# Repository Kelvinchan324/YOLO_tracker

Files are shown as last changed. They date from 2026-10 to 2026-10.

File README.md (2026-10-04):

# YOLO Camera Tracker

Mechanical design files for a two-axis camera and sensor tracker intended for
YOLO-based object-tracking projects.

## Teaching materials

- [`Workshop: Build Your Own YOLO Tracker`](teaching_materials/Workshop_Build_Your_Own_YOLO_Tracker.pdf)
  - the complete 65-page assembly, wiring, calibration, and testing guide.

## Gimbal control software

The [`software`](software) directory contains a Raspberry Pi controller for
the two STS3215 motors used by the workshop tracker. It uses servo ID `1` for
yaw and servo ID `2` for pitch, reads each unit's current center position, and
supports manual arrow-key control through the ESP32 driver's serial-forwarding
mode. The [software instructions](software/README.md) include a dedicated
Raspberry Pi Python and `scservo_sdk` setup section; read it before powering
the motors.

## CAD contents

The [`cad`](cad) directory contains the original SolidWorks models and
assemblies, along with neutral CAD exports where available.

- `cad/camera tracker with laser/` — current SolidWorks tracker parts and the
  `camer_tracker.SLDASM` top-level assembly.
- `cad/3D printing files/` — the grouped design files previously packaged as
  the sharing revision.
- `cad/educational version/` — simplified educational tracker design, including the main
  `camer_tracker_easy.SLDASM` assembly and electronics enclosure.
- `cad/distance_sensor-1.snapshot.12/` — distance-sensor reference model,
  images, datasheet, and STEP files.

## File formats

| Extension | Purpose |
| --- | --- |
| `.SLDASM` | SolidWorks assembly |
| `.SLDPRT` | SolidWorks part |
| `.STEP` | Neutral CAD exchange file |

SolidWorks assemblies reference their part files by name. Keep the relevant
assembly and its component files together when downloading or moving them.

## Getting started

For the camera tracker with laser, open
`cad/camera tracker with laser/camer_tracker.SLDASM` in SolidWorks. For the
simplified design, open `cad/educational version/camer_tracker_easy.SLDASM`.

Archive files that duplicated folders already included in this repository were
left out to avoid storing the same large binary files twice.

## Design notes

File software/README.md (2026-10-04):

# STS3215 Gimbal Controller

This controller follows the workshop setup:

- yaw motor: STS3215 servo ID `1`
- pitch motor: STS3215 servo ID `2`
- connection: ESP32 servo driver in `SERIAL_FORWARDING` mode
- serial device: `/dev/ttyUSB0`
- baud rate: `115,200`

The two motors are daisy-chained. The ESP32 driver is connected to the
Raspberry Pi by USB-C and powered separately by the 12 V servo supply.

## Safety before running

1. Assemble the gimbal and connect the servo cables in the orientation shown
   in the workshop notes.
2. Position the camera approximately forward and level by hand.
3. Keep hands and loose cables clear of the gears.
4. Power the ESP32 servo driver with the correct 12 V supply.
5. Confirm its display detects servo IDs `1` and `2` and enters
   `SERIAL_FORWARDING` mode.

The program reads the current positions on startup and treats them as the
center. It does not command either motor until you press a movement key.

## Install

On the Raspberry Pi:

```bash
cd software
python3 -m venv .venv
source .venv/bin/activate
python3 -m pip install -r requirements.txt
```

## Raspberry Pi control with Python and `scservo_sdk`

The controller uses the Feetech `scservo_sdk` package directly. The workshop
ESP32 board forwards commands at `115200` baud; this differs from the
STS3215's direct-bus factory baud rate. The Raspberry Pi port can change when
USB devices are reconnected, so find it before running the program:

```bash
dmesg | grep -i cp210x
python3 -m serial.tools.list_ports
ls -l /dev/ttyUSB*
```

Look for the CP210x adapter and use the corresponding device, commonly
`/dev/ttyUSB0` or `/dev/ttyUSB1`. Test communication without moving either
motor:

```bash
python3 gimbal_controller.py \
  --port /dev/ttyUSB0 \
  --baudrate 115200 \
  --calibrate-only
```

The essential `scservo_sdk` pattern used by the controller is:

```python
from scservo_sdk import COMM_SUCCESS, PortHandler, sms_sts

port = PortHandler("/dev/ttyUSB0")
servos = sms_sts(port)

if not port.openPort():
    raise RuntimeError("Could not open the serial port")

try:
    if not port.setBaudRate(115200):
        raise RuntimeError("Could not set the ESP32 forwarding baud rate")

    # ID 1 is yaw; ID 2 is pitch.
    yaw_position, result, error = servos.ReadPos(1)
    if result != COMM_SUCCESS or error:
        raise RuntimeError("Could not read yaw servo")

    pitch_position, result, error = servos.ReadPos(2)
    if result != COMM_SUCCESS or error:
        raise RuntimeError("Could not read pitch servo")

    print(f"Yaw center: {yaw_position}, pitch center: {pitch_position}")

    # WritePosEx(servo_id, target_position, speed, acceleration)
    # Use measured, mechanically safe targets between 0 and 4095.
    result, error = servos.WritePosEx(1, yaw_position, 500, 50)
    if result != COMM_SUCCESS or error:
        raise RuntimeError("Could not command yaw servo")
finally:
    port.closePort()
```

Use `ReadPos()` to obtain each tracker's unique center before commanding any
movement. `WritePosEx()` accepts the servo ID, a target from `0` to `4095`,
speed, and acceleration. The full `gimbal_controller.py` wraps these calls
with arrow-key input, limit checking, communication-error reporting, and
automatic serial-port cleanup.

If the Raspberry Pi reports a serial-port permission error, add the current
user to the `dialout` group and then sign out and back in:

```bash
sudo usermod -aG dialout "$USER"
```

## Calibrate and control

First read the two center positions without moving the gimbal:

```bash
python3 gimbal_controller.py --calibrate-only
```

Record the displayed yaw and pitch values, as required by the workshop notes.
Then start keyboard control:

```bash
python3 gimbal_controller.py
```

Controls:

- Left/Right: yaw
- Up/Down: pitch
- `C`: return to the center recorded at startup
- `R`: use the current measured positions as new centers
- `P`: display the current measured positions
- `Esc` or `Q`: quit

If an axis moves in the opposite direction, use `--invert-yaw` or
`--invert-pitch`. To limit travel for a particular build, set safe position
ranges. For example:

```bash
python3 gimbal_controller.py \
  --yaw-min 100 --yaw-max 4000 \
  --pitch-min 1800 --pitch-max 3100
```

Run `python3 gimbal_controller.py --help` for all options, including motor
IDs, serial port, step size, speed, and acceleration.

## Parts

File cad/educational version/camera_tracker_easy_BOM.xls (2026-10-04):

ITEM NO. | PART NUMBER | TYPE | QTY. | DESCRIPTION | Link
1 | camera_case | 3D print | 1
2 | camera_cover | 3D print | 1
3 | camera_tracker_bearing_mount | 3D print | 1
4 | U_mount | 3D print | 1
5 | camer_tracker_base_cover | 3D print | 1
6 | base_bearing_cover | 3D print | 1
7 | base_gear_bigger | 3D print | 1
8 | base_gear_smaller_easy | 3D print | 1
9 | camera_tracker_base | 3D print | 1
10 | electronics_box | 3D print | 1
11 | electronics_box_cover | 3D print | 1
12 | ENGG1101_webcam | Electronics | 1
13 | servoFeetechSTS3215_tracker | Electronics | 2
14 | STS3215_metal_horn_tracker | Electronics | 2
15 | 30_42_7_bearing | Bearing | 1
16 | M3*6 Screws | Screws | 10
17 | M3*8 Screws | Screws | 8
18 | M3*15 Screws | Screws | 2
19 | M3*30 Screws | Screws | 4
20 | Servo motor Screws Pack | Screws | 4
21 | M3 Nuts | Nuts | 4
22 | Monitor | Control & Display | 1
23 | Keyboard & Mouse | Control & Display | 1
24 | Micro HTMI Cable | Control & Display | 1
74 | RASPBERRY_PI_5 |  | 1

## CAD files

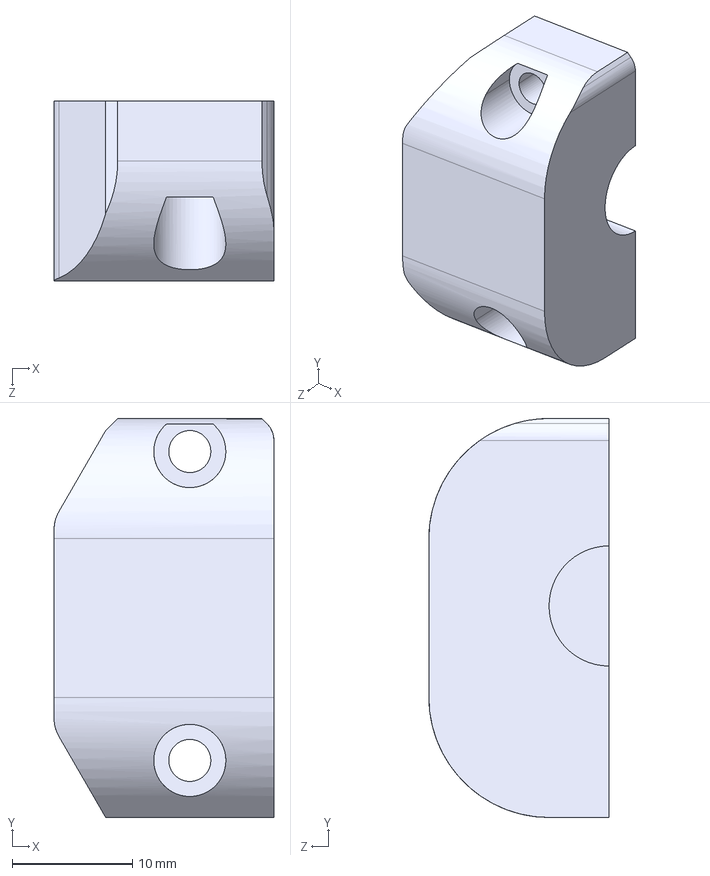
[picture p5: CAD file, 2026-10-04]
cad/camera_tracker_bearing_mount.STEP
18.3 x 33.2 x 15.0 mm

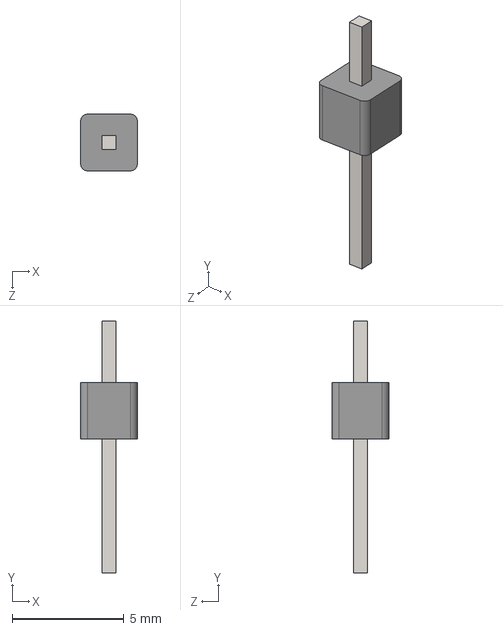
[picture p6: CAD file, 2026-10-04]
cad/distance_sensor-1.snapshot.12/STEP/headerPin.STEP
2.54 x 11.3 x 2.54 mm

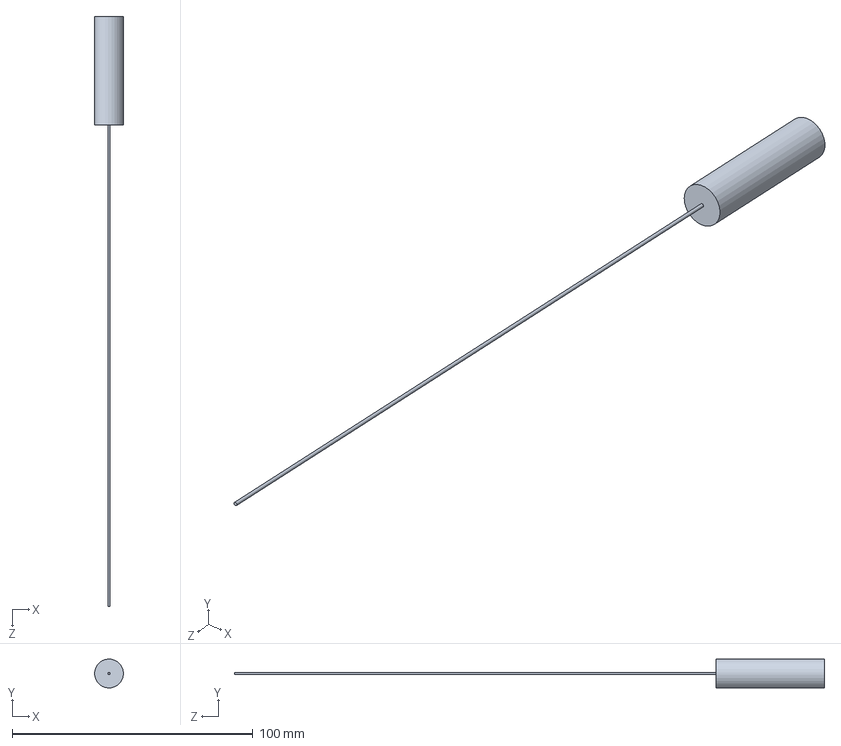
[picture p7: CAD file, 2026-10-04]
cad/educational version/laser_ponter.SLDPRT
12.0 x 12.0 x 245.0 mm

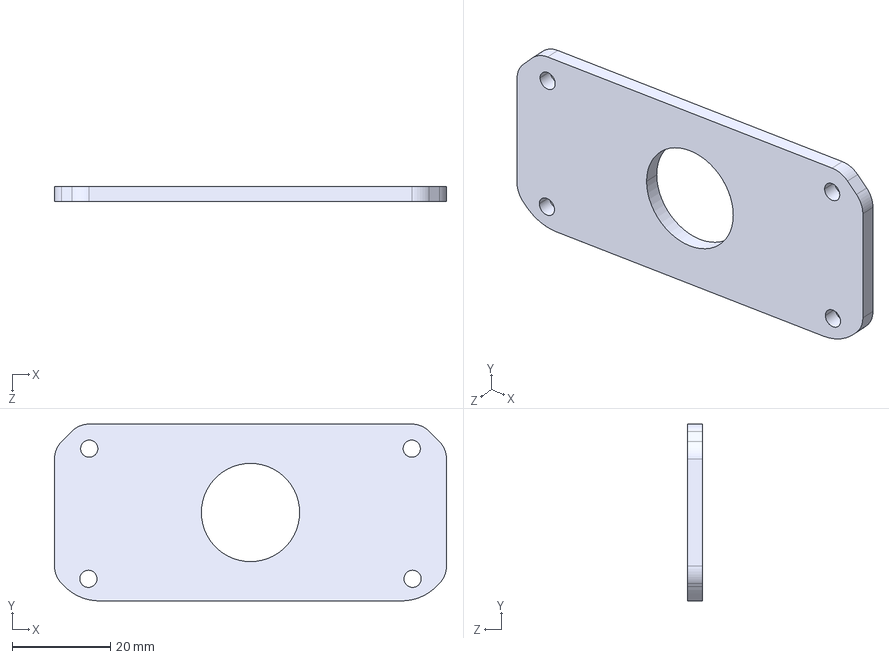
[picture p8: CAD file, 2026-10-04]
cad/camera_cover.STEP
79.8 x 36.0 x 3.00 mm

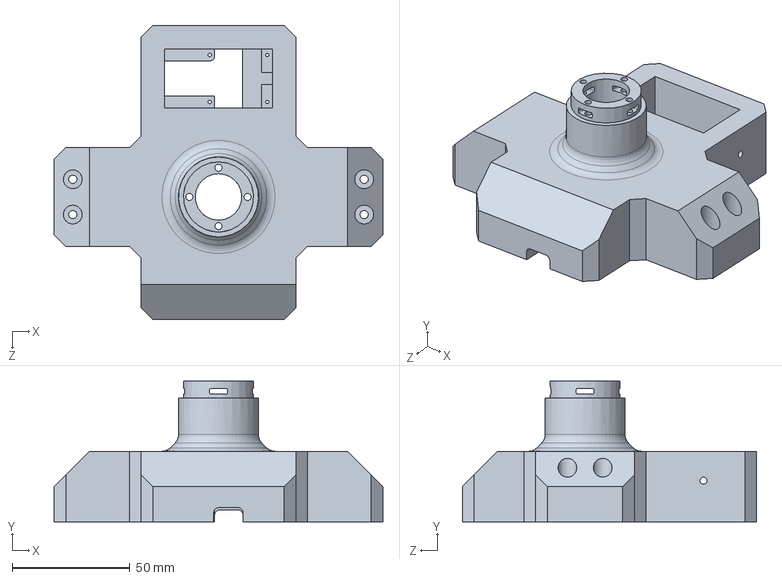
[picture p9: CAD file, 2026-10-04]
cad/educational version/camera_tracker_base.SLDPRT
140.0 x 59.8 x 125.2 mm

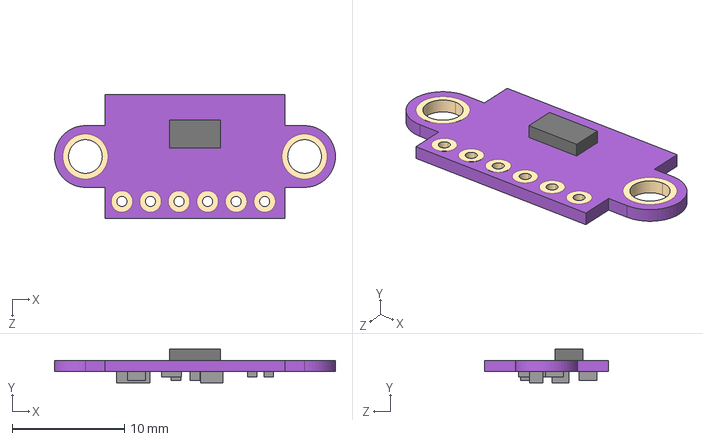
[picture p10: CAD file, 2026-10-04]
cad/distance_sensor-1.snapshot.12/STEP/sensor.STEP
25.0 x 3.00 x 11.0 mm

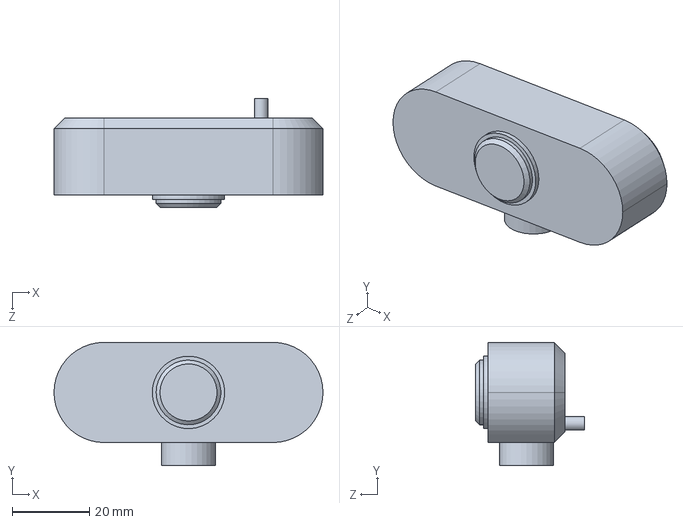
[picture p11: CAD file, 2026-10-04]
cad/educational version/ENGG1101_webcam.SLDPRT
69.8 x 32.0 x 28.2 mm

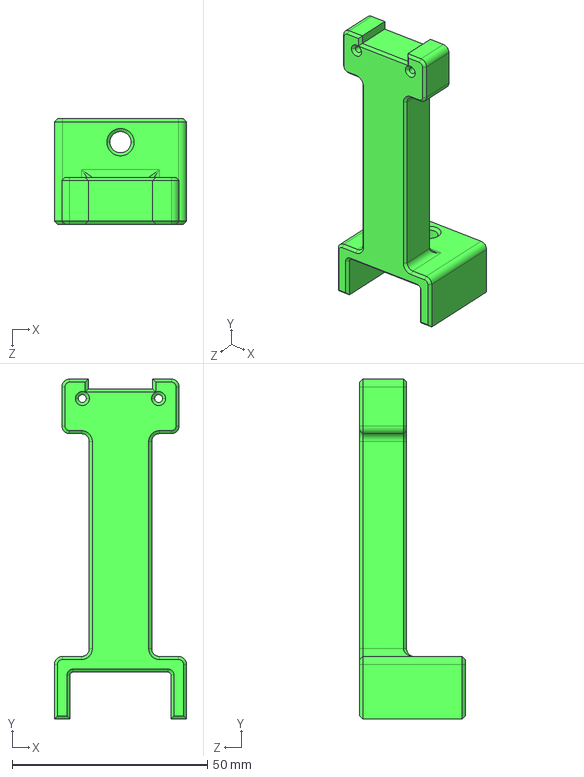
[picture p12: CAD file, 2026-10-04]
cad/distance_sensor-1.snapshot.12/STEP/bracket.STEP
33.8 x 87.0 x 27.0 mm

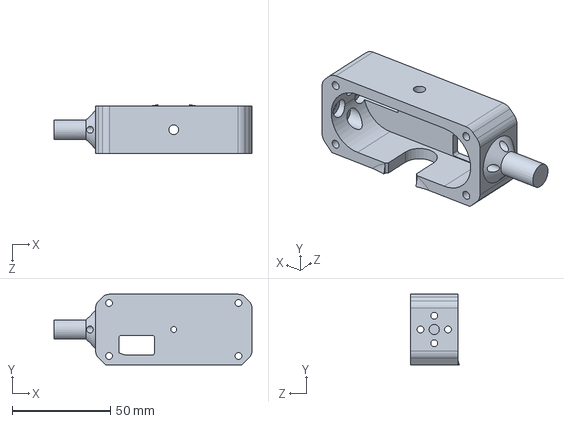
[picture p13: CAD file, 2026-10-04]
cad/educational version/camera_case.SLDPRT
101.0 x 36.0 x 24.8 mm

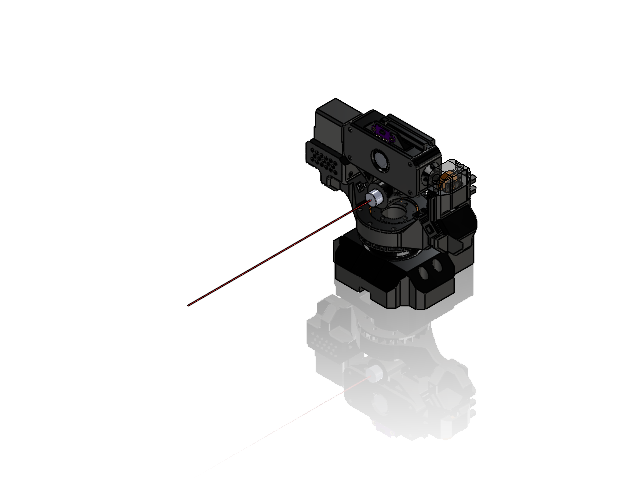
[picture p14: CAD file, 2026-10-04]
cad/3D printing files/camer_tracker.SLDASM
ENGG1101_webcam
servoFeetechSTS3215_tracker x 2
STS3215_metal_horn_tracker x 2
camera_case
sensor
headerPin x 6
camera_cover
10_20_5_bearing
30_42_7_bearing
laser_ponter
U_mount
base_gear_smaller
base_gear_bigger
camera_tracker_bearing_mount
camera_tracker_base
base_bearing_cover
camer_tracker_base_cover

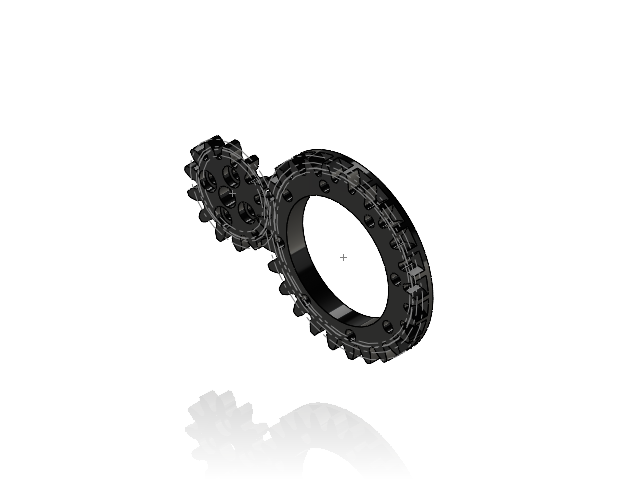
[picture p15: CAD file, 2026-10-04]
cad/educational version/base_gear_assem.SLDASM
base_gear_smaller
base_gear_bigger

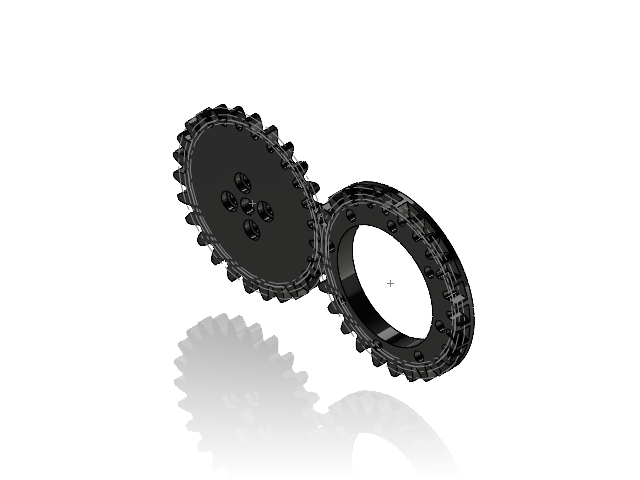
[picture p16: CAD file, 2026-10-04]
cad/educational version/camera_tracker_easy_gear.SLDASM
base_gear_smaller_easy
base_gear_bigger

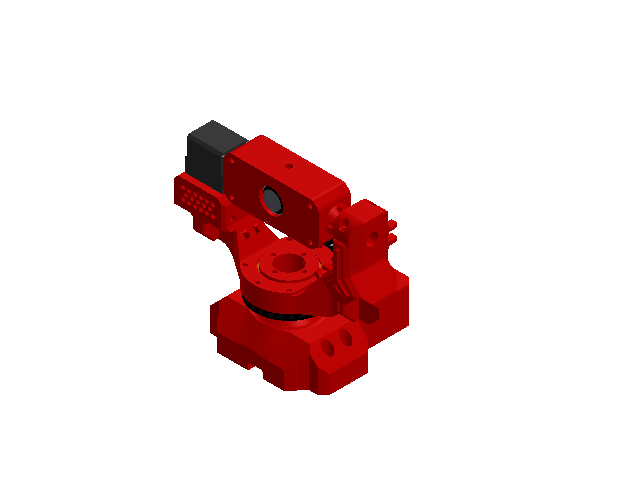
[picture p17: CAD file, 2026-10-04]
cad/educational version/camer_tracker_easy.SLDASM
ENGG1101_webcam
servoFeetechSTS3215_tracker x 2
STS3215_metal_horn_tracker x 2
camera_case
camera_cover
30_42_7_bearing
U_mount
camera_tracker_bearing_mount
camera_tracker_base
camer_tracker_base_cover
base_gear_smaller_easy
base_gear_bigger
base_bearing_cover

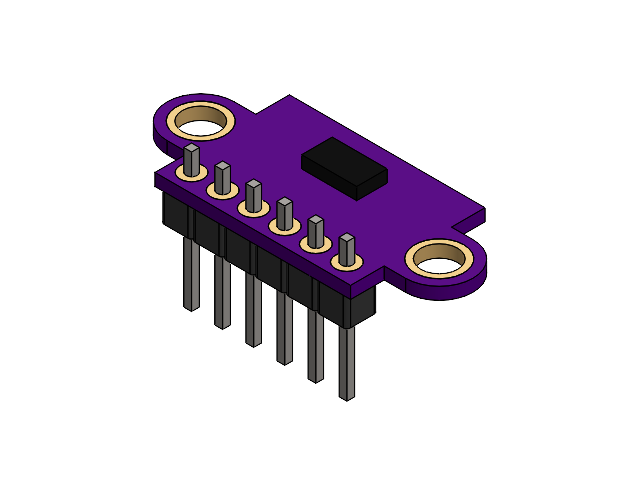
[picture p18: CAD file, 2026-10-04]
cad/educational version/sensor_assy.SLDASM
sensor
headerPin x 6

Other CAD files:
cad/distance_sensor-1.snapshot.12/STEP/sensor_assy.STEP
cad/camera tracker with laser/camer_tracker.SLDASM
cad/educational version/camera_tracker_bearing_mount.STEP
cad/educational version/sensor.SLDPRT
cad/3D printing files/10_20_5_bearing.SLDPRT
cad/3D printing files/30_42_7_bearing.SLDPRT
cad/3D printing files/ENGG1101_webcam.SLDPRT
cad/3D printing files/STS3215_metal_horn_tracker.SLDPRT
cad/3D printing files/U_mount.SLDPRT
cad/3D printing files/base_bearing_cover.SLDPRT
cad/3D printing files/base_gear_assem.SLDASM
cad/3D printing files/base_gear_bigger.SLDPRT
cad/3D printing files/base_gear_smaller.SLDPRT
cad/3D printing files/camer_tracker_base_cover.SLDPRT
cad/3D printing files/camera_case.SLDPRT
cad/3D printing files/camera_cover.SLDPRT
cad/3D printing files/camera_tracker_base.SLDPRT
cad/3D printing files/camera_tracker_bearing_mount.SLDPRT
cad/3D printing files/headerPin.SLDPRT
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

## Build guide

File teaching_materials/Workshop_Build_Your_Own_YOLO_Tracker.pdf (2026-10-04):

# Workshop: Build Your Own YOLO Tracker

## Objectives

After finishing this workshop, you should:

1. Be able to build a human tracking robot on your own
2. Learn the basics of how computer vision works
3. Enjoy building Robots !!!

## Estimated Time

1.5 to 2 hours

YOLO tracker and workshop notes designed by Mr. Kelvin Chan

Ideas based on ENGG1101 mini-project (YOLO tracker on drones) by Dr. Ryan Wang

Present by: HKU Active Learning Team

(Lectures: Dr. Ryan Wang, Dr. Edwin Dung, Dr. Timmy Cheng, Mr. Kyle Ho)

(TAs: Mr. Kelvin Chan, Mr. Karlos Ma, Mr. Sum Cheung, Mr. Henry Tang)

# Warm Up & Form Your Team

## Find your Teammates and collect the materials

1. Collect your workshop materials from the teaching team
Workshop: Build Your Own YOLO Tracker | 1

2. Introduce yourselves to your teammates

You should get a material box with the following items:

Material Box Bill of Materials (MB-BOM):

Items | Amount | Remarks
3D Printed parts | 9 | Check if you have all the different types of 3D printed part as shown
Servo Motor Wires | 2 | 260mm long 3 pin wire
Bearing | 1 | 30*42*7 Bearing
Hex Keys | 3 | M3 hex key with handles
Spanners | 3 | 5.5mm & 7mm spanner
USB-C Cable | 1

Check if you got all the materials, if not please raise your hand and ask

Other than the material box, you should also get a set of extra materials,

Extra Materials Bill of Materials (EM-BOM):

Items | Amount | Remarks
3D Printed parts | 2 | Electronic Box base and cover
Servo Motors | 2 | 12V STS3215 Servo Motors
ESP32 Servo Motor Driver | 1 | Black Driver Board for controlling STS3215 Servo Motors
Raspberry Pi | 1 | Main controlling unit
USB camera | 1
M2 Hex key | 1
Crossed Screw Driver | 1
Screws and nuts set | 1

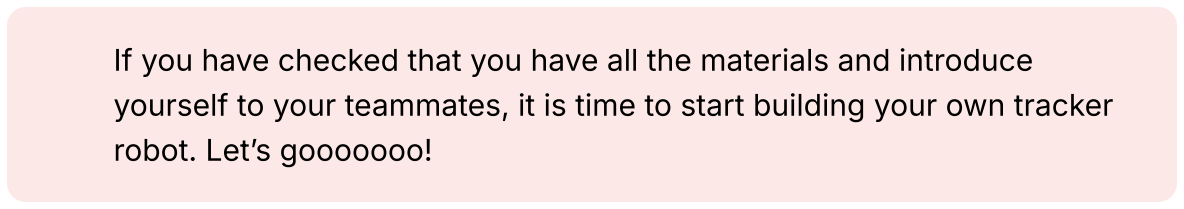
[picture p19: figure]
robot. Let’s gooooooo!

If you have checked that you have all the materials and introduce yourself to your teammates, it is time to start building your own tracker

# Assembling Your Human Tracker

### Part 1: Assembling the Rotation Part

In this part, we would start by building the middle yaw rotating part of

You would need the following materials in this part:

Items | Amount
3D Printed U shaped mount (largest) | 1

3D printed Gear part (one with flat surface) | 1
3D printed cover part (cut circle) | 1
Bearing | 1
M3 screws (8mm long) | 8
M3 Screws (6mm long) | 6

First, we put the bearing in the “3D printed U shaped mount” as shown below.

You may have to use some force to push it in.
But be careful, don’t break the 3D printed part (or yourself).

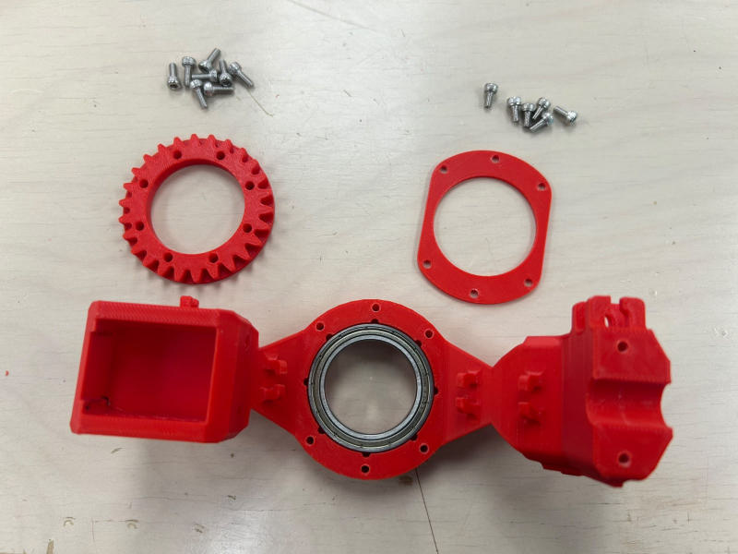
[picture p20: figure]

Place the “3D printed cover part” on top of the bearing, Insert 6mm long M3 screws to the 6 holes and align it with the “3D printed U shaped mount”

Screw in the part with a hex key. Tighten the parts until you feel a sudden increase of resistant force.

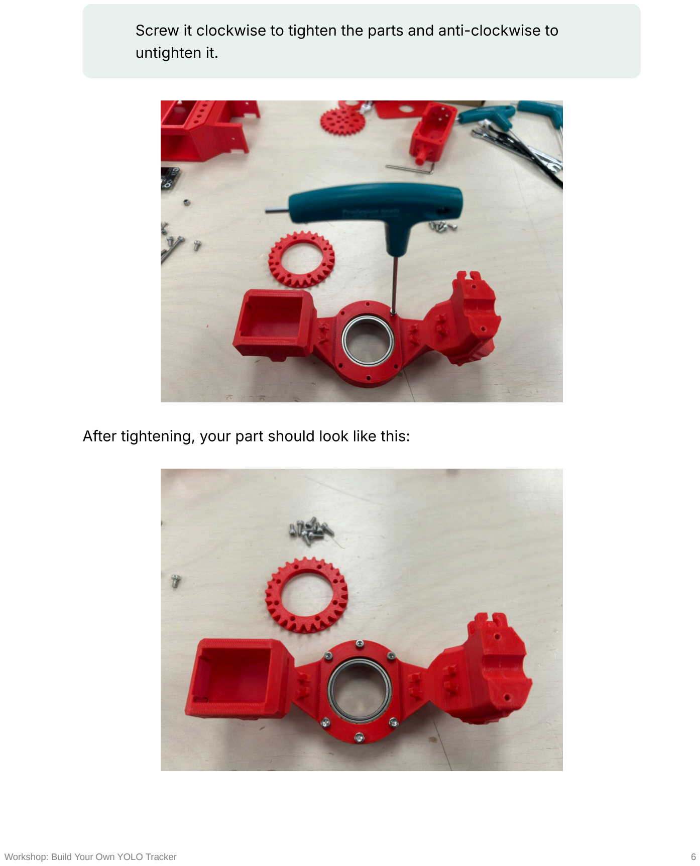
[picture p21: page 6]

Screw it clockwise to tighten the parts and anti-clockwise to untighten it.

After tightening, your part should look like this:

Flip the “3D printed U shaped mount” over and place the “3D printed Gear part” on top.

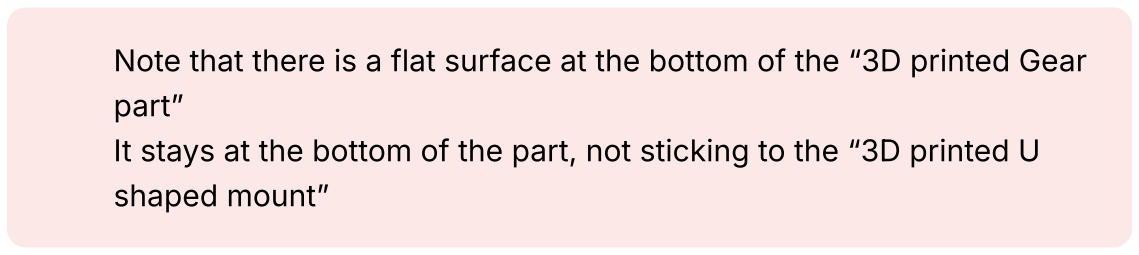
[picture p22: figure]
part”; shaped mount”

Note that there is a flat surface at the bottom of the “3D printed Gear

It stays at the bottom of the part, not sticking to the “3D printed U

Align the holes and tighten the parts using 8mm long M3 screws just like what you did.

After tightening, your part should look like this from the top with a gear attached at the bottom

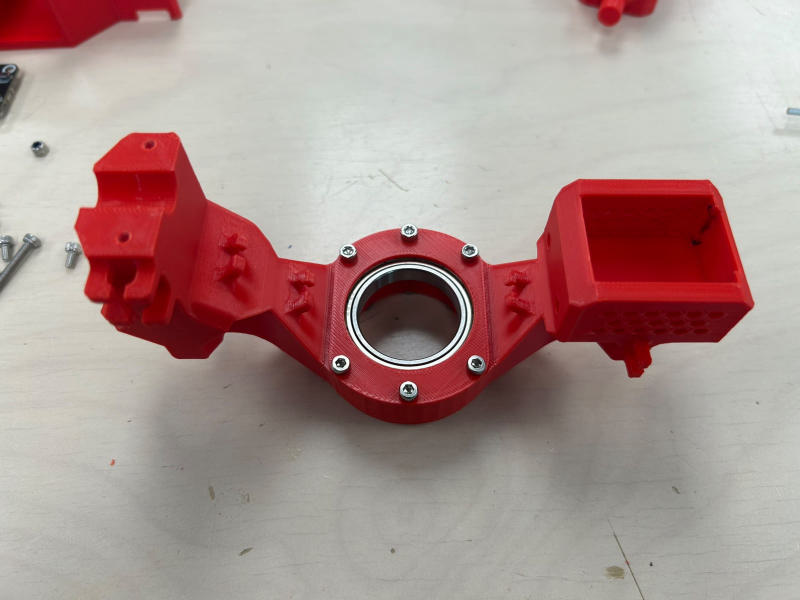
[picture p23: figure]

Yea, and you just finished Part 1. Good job, let’s move to the next part

### Part 2: Assembling the Camera Mounting Part

In this part, we would building the camera mounting part and pitch

You would need the following materials in this part:

Items | Amount
3D Printed camera housing with rod | 1
3D printed camera cover | 1
STS3215 Servo Motor (Motor 2) | 1
USB camera | 1
M3 screws (30mm long) | 4
Crossed Servo Motor Screws (M3*6) | 4
M3 Nuts | 4

Before assembling the part, notice that there are two sides of the

Output Side: the side with Metal Gear Teeth

Back Side: the opposite side with smooth plastic

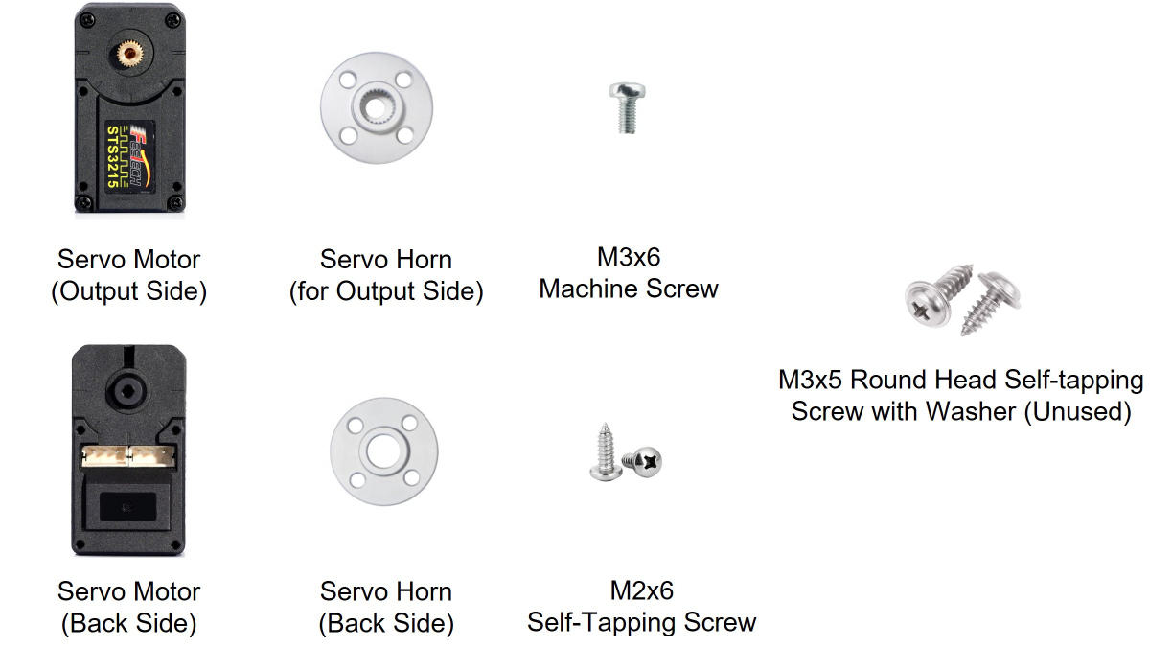
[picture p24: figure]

For the output side, we need to attach the servo horn with gears (teeth).

For the backside, we could just use a smooth servo horn acting as a bearing

Alight, back to assembling the part, we only need to install the metal servo horns on the output side for this project.

First, align the four holes on “3D Printed camera housing with rod” to the holes on the servo horn attached to the output side of the servo motor.

In this part we use MOTOR 2, which has a sticker labeled with 2

Insert the servo motor screws (cross-headed) to each of the holes and tighten them using the cross screw driver provided.

After tightening, your part should look like this:

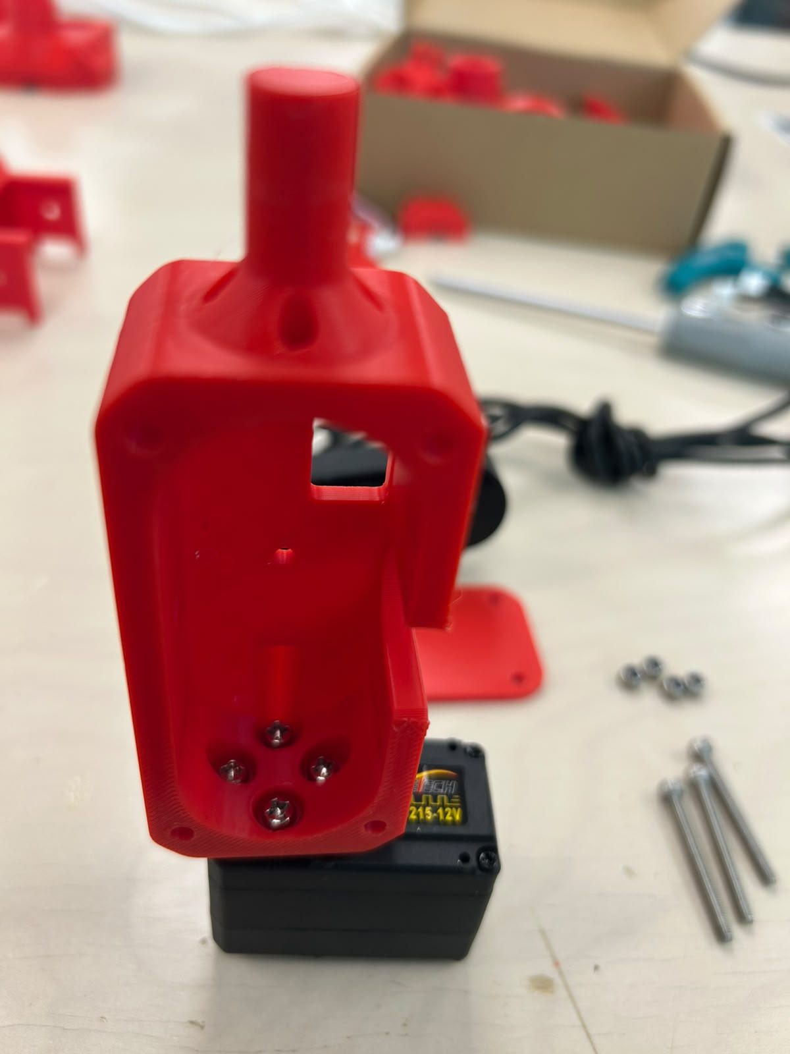
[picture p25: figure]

Wire the USB end of the USB camera though the square slot on the bottom right of the “3D Printed camera housing with rod”

Insert the camera into the 3D printed part, it should be a tight fit.

Place the “3D printed camera cover” on top and insert 4 M3 screws (30mm long) to all the holes, passing through both 3D printed parts.

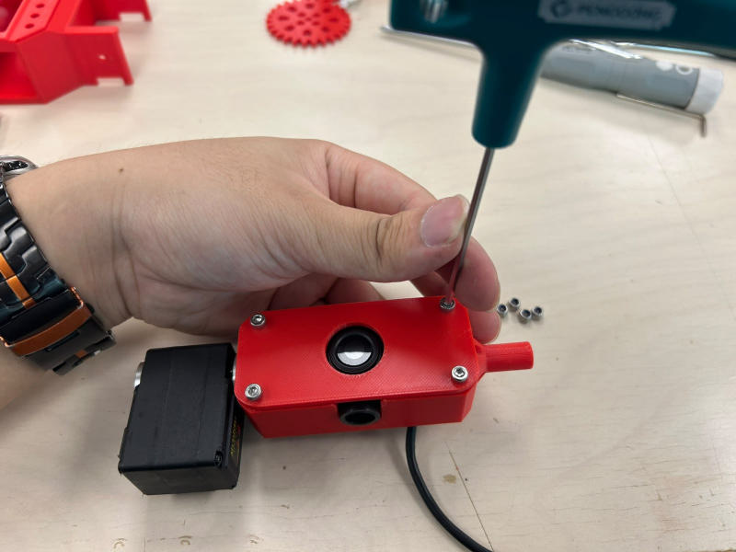
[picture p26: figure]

Place the M3 Nuts on the screws by rotating them in clockwise (with hand or spanner)

Fix the orientation of the M3 nuts using the spanner (5.5mm end) at the back and at the same time rotate the M3 hex key clockwise to tighten the two 3D printed parts as shown:

After tightening, your part should look like this from the top with a camera protected with a 3D printed housing and a servo motor at one side.

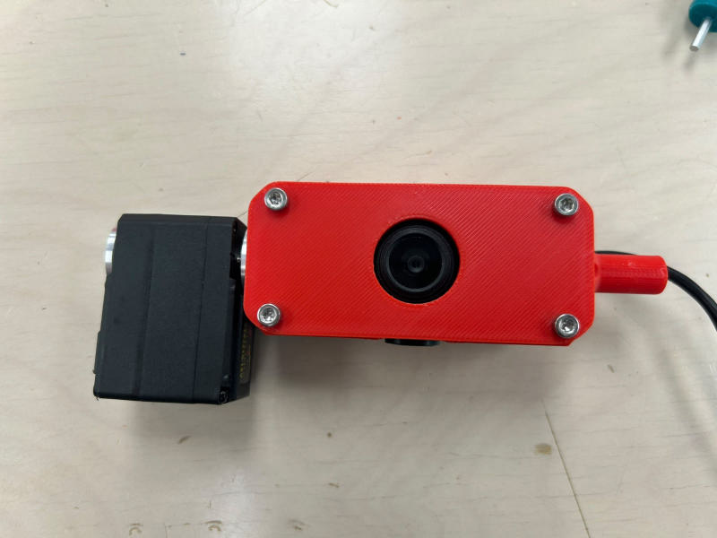
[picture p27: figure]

That’s all for Part 2, are you enjoying it?

### Part 3: Assembling the Base

In this part, we would connect the rotation part we build in Part 1 with

You would need the following materials in this part:

Items | Amount
Finished part from “Part 1” | 1
3D printed base | 1
3D printed Gear part (one without flat surface) | 1
3D printed bearing cover (circle) | 1
STS3215 Servo Motor (Motor 1) | 1
M3 screws (6mm long) | 4
Crossed Servo Motor Screws (M3*6) | 4

Place the servo motor at back of the “3D printed base”

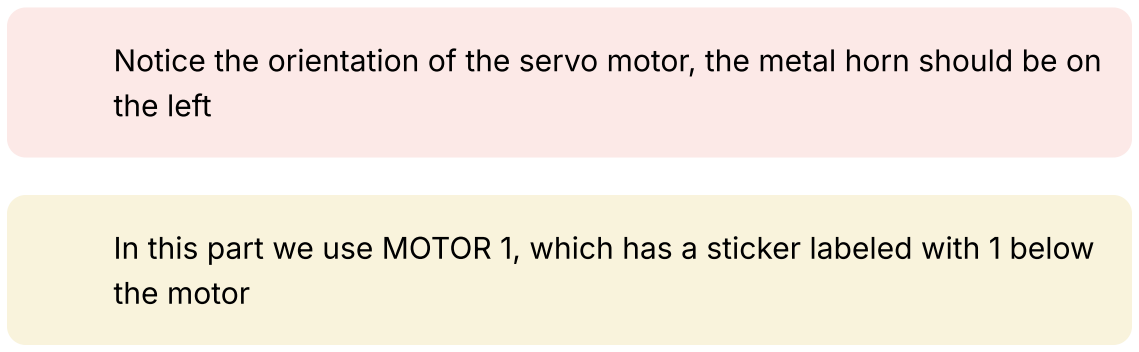
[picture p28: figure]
the left; the motor

Notice the orientation of the servo motor, the metal horn should be on

In this part we use MOTOR 1, which has a sticker labeled with 1 below

Insert the “3D printed Gear part (one without flat surface)” to the Finished part from “Part 1”

The teeth of the gears should be aligned

Place the whole part onto the base. The bearing should be sitting on the circle part attached to the base as shown:

Align the holes on the 3D printed gear and the servo motor horn.

Screw in the parts with cross-headed servo motor screws using the screw driver

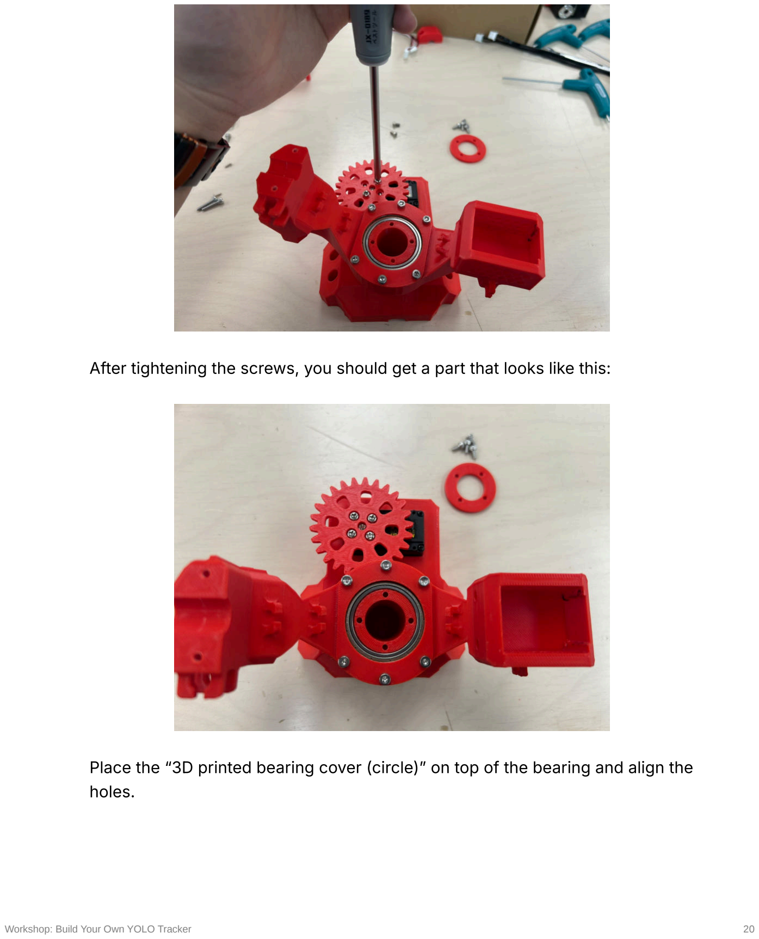
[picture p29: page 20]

After tightening the screws, you should get a part that looks like this:

Place the “3D printed bearing cover (circle)” on top of the bearing and align the holes.

Tighten the parts with 6mm M3 screws using the hex key

After tightening the screws, you should get a part that looks like this:

Now, you’ve got rotating base for the tracker.

### Part 4: Assembling the Main Body

In this part, we would finish building the main part of the tracker

You would need the following materials in this part:

Items | Amount
Finished part from “Part 2” | 1
Finished part from “Part 3” | 1
3D printed rod mounting part | 1
Shape-headed Servo Motor Screws | 2
M3 screws (15mm long) | 2

Insert the “Finished part from “Part 2”” on the “Finished part from “Part 3”” as shown:

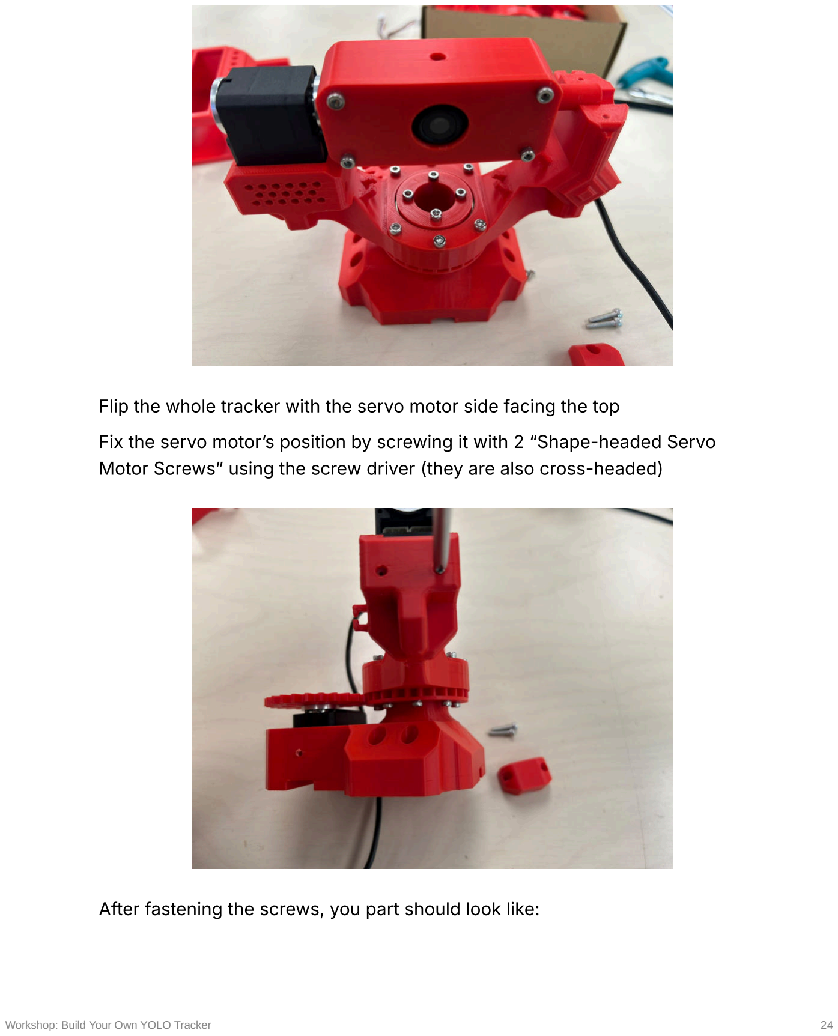
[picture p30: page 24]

Flip the whole tracker with the servo motor side facing the top

Fix the servo motor’s position by screwing it with 2 “Shape-headed Servo Motor Screws” using the screw driver (they are also cross-headed)

After fastening the screws, you part should look like:

Don’t worry if your servo motor does not have the servo motor horn, it does not matter and will not affect our tracker

Place the “3D printed rod mounting part” on top of the opposite side of the tracker.

The part should support the rod from the camera housing

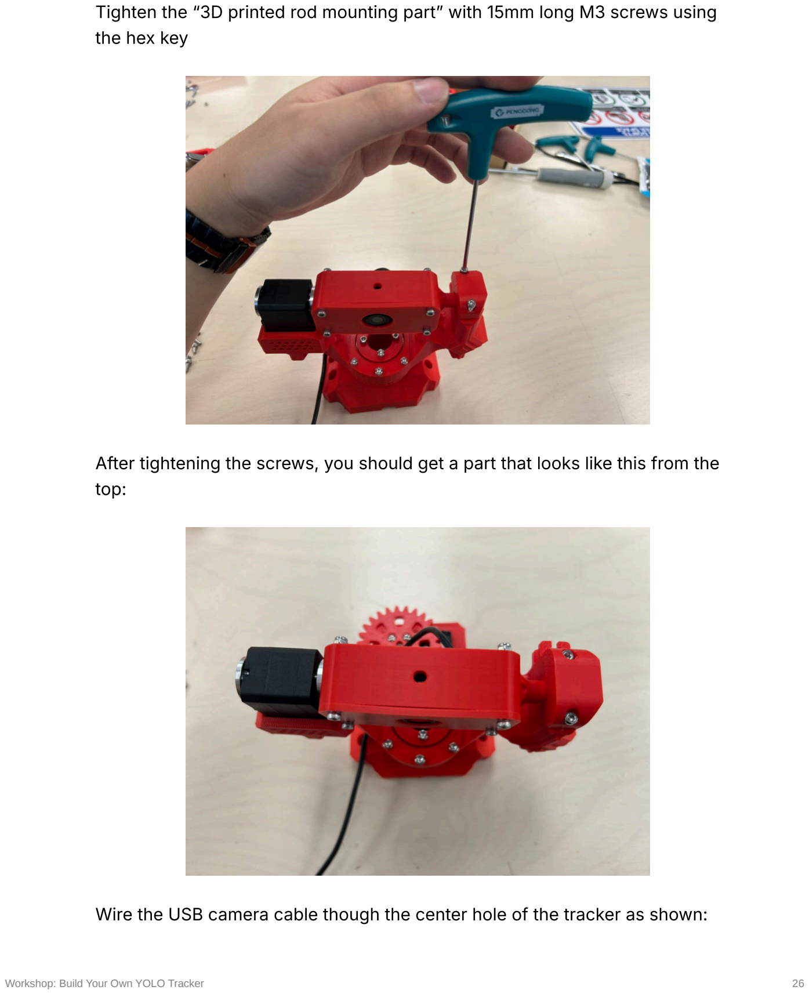
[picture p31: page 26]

Tighten the “3D printed rod mounting part” with 15mm long M3 screws using the hex key

After tightening the screws, you should get a part that looks like this from the top:

Wire the USB camera cable though the center hole of the tracker as shown:

This is how it should look like from the bottom

This is how it should looks after you finish all mechanical parts:

You can see now the main tracker part is done with one USB camera cable at the bottom.

You should also see that there are two motor wires not use being used yet.

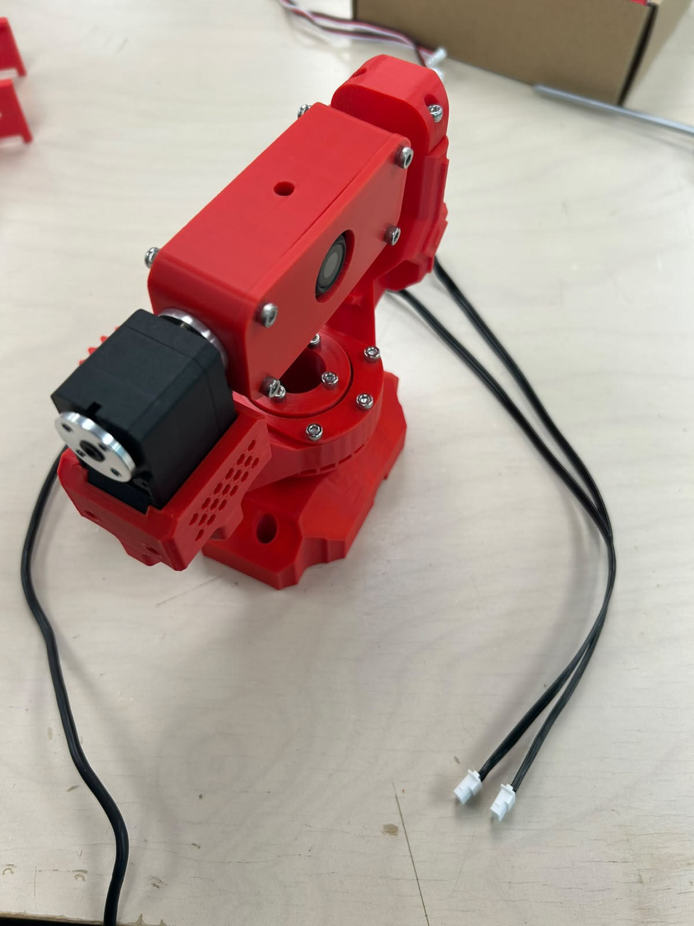
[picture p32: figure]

This is why we will start wiring the motors now

Notice the wire direction before plugging in the motor.

The side WITHOUT metal pin holes should face upwards

Press the wire into the header on the servo motor

You may have to press it tightly until it plugs in (usually it requires a “little bit” of force)

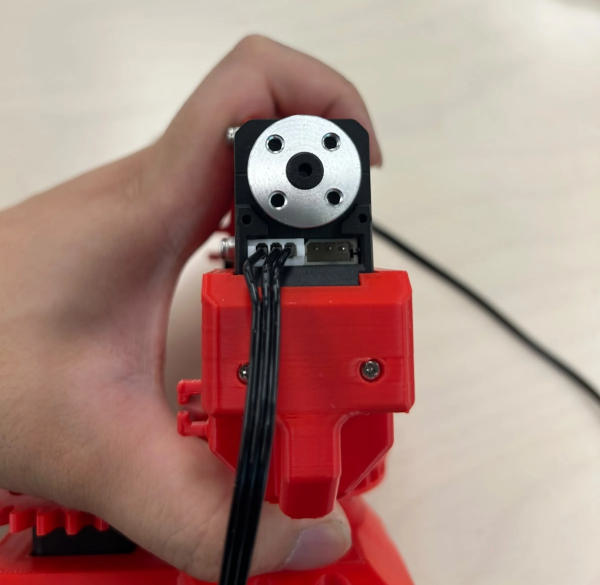
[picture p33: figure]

Wire the other end of the servo motor wire though the center tracker hole

Connect the other side of the servo motor wire to the servo motor on the base

AGAIN!!! remember that the orientation of the wire matters

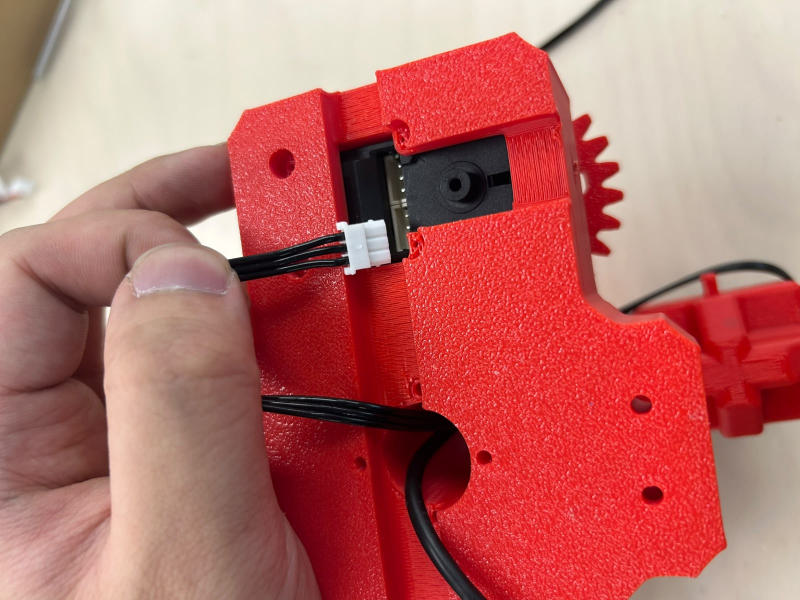
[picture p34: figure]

Plug in the wire. On the other header of the servo motor, connect one end of the second servo motor wire.

After this, you should get a tracker with two wires/cables extending out

One for the servo motor signals and one for the USB camera signals

Now the main tracker part is done. But we cannot control it yet, we

### Part 5: Assembling the Control Unit

In this part, we would build and wire the control unit box

### Session A: Raspberry Pi

You would need the following materials in this session:

Items | Amount
Finished part from “Part 4” | 1
3D printed Electronics Box | 1
Raspberry Pi | 1

Wire the USB camera wire and Servo Motor wire though the front hole of the “3D printed Electronics Box”

Attach the “3D printed Electronics Box” to the end of the tracker as shown:

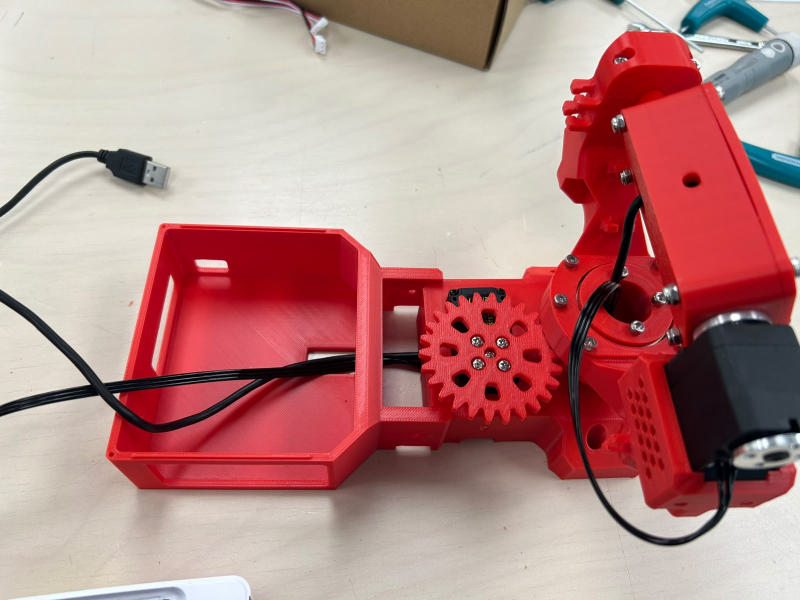
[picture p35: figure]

Wire the USB camera cable through the side hole and place the Raspberry Pi in the “3D printed Electronics Box”

Plug the USB end of the camera cable to the Raspberry Pi USB slot

You can use any of the four slots, but i choose the right upper one.

Tidy up the cable and insert it in the “3D printed Electronics Box” for tidiness

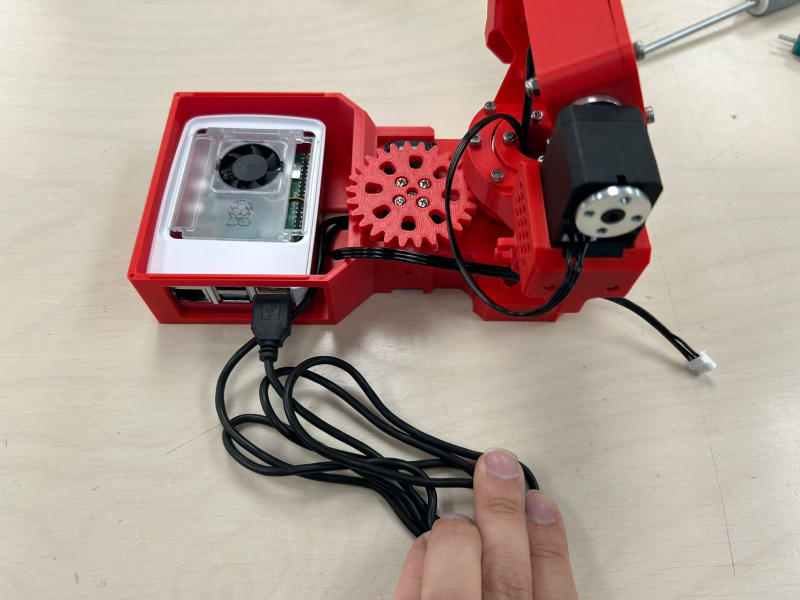
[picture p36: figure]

### Session B: ESP32 servo motor driver

You would need the following materials in this session:

Items | Amount
ESP32 servo motor driver | 1
3D printed Electronics Box Cover | 1

M3 screws (6/8mm long) | 4

Flip the “3D printed Electronics Box Cover” and place the ESP32 servo motor driver in.

Align the holes in both parts.

Fix the ESP32 driver in place by screwing in 6/8mm M3 screws with the hex key.

Repeat the same for all four holes.

Pass the servo motor wire though the slot on the “3D printed Electronics Box Cover”

Plug in the servo motor wire to the ESP32 servo motor driver upper port

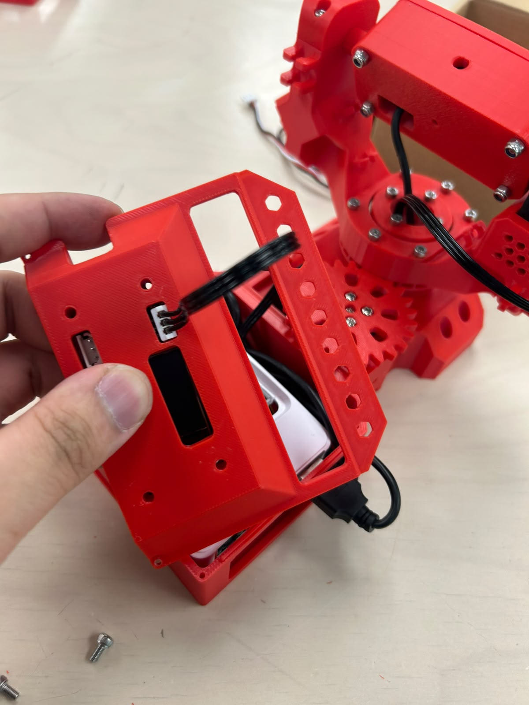
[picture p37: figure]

Slide in the cover and fix it using two 8mm long M2 screws.

This time you would need a M2 hex key instead of the one with a

You tracker should look similar with the you shown below:

Now, connect the USB end of the USB-C cable to the Raspberry Pi USB slot

(any USB slot among the 4)

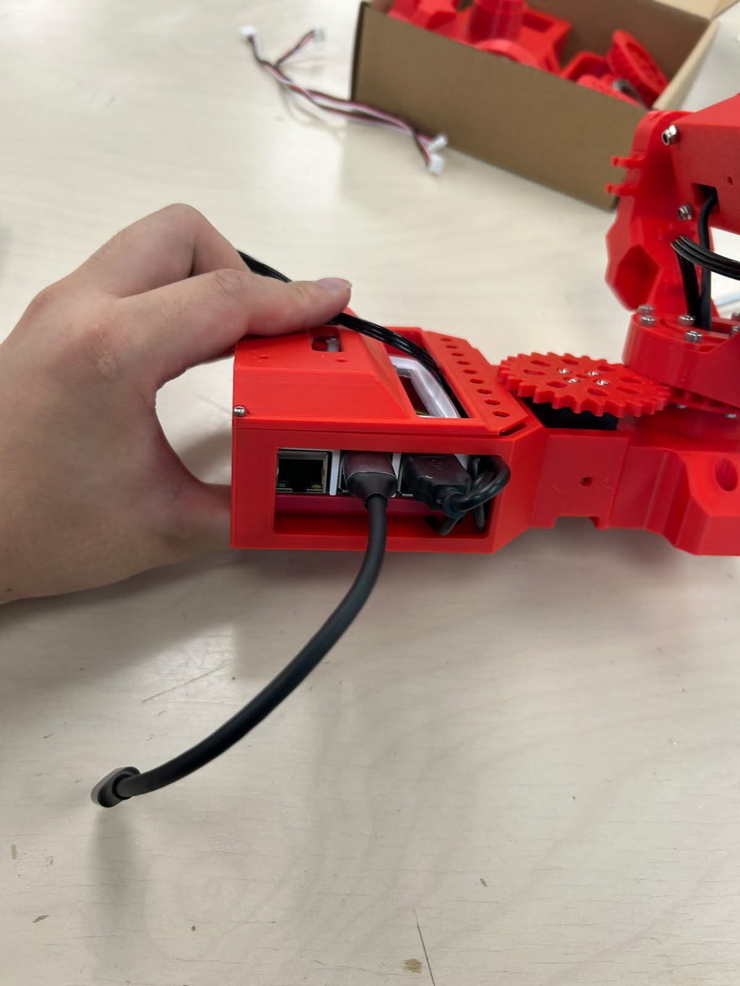
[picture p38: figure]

On the other end (USB-C) connect to the ESP32 servo motor driver USB-C port.

Be careful not to move it up and down, or you may damage the port

Now you had finished assembling all the parts of the Human tracking

# Testing Your Human Tracker

### Part 1: Wiring the Display & Controls

You would need the following materials in this Part:

Items | Amount
Monitor | 1
Keyboard & Mouse | 1
Micro-HDMI to HDMI Cable | 1
12V Servo Motor Power Supply | 1
5V 5A Raspberry Pi Power Supply | 1
USB-C power for monitor | 1

First, take the Bluetooth adapter for the keyboard & mouse from the back of it. The adapter is located at the cover of the battery slot.

Plug the Bluetooth adapter to the Raspberry Pi USB port

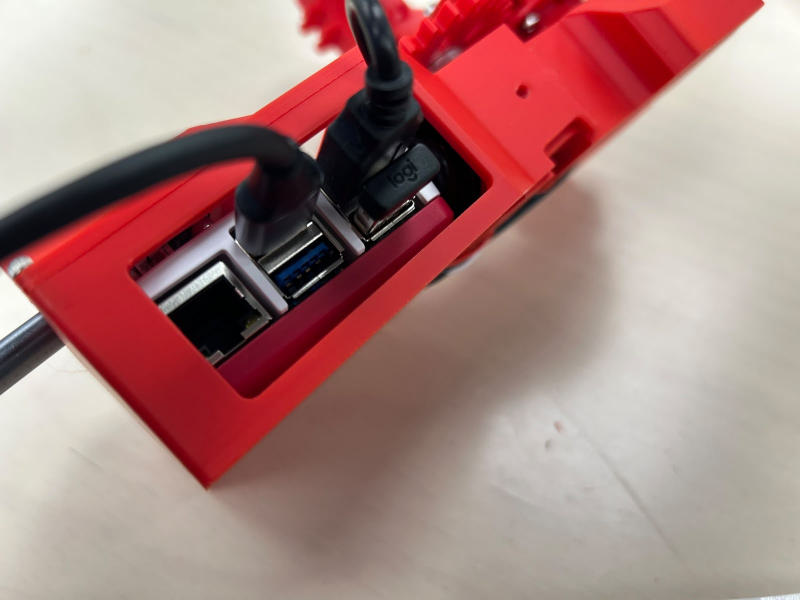
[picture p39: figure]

Connect the micro-HDMI end of the HDMI cable to the raspberry HDMI port

The Raspberry Pi HDMI port is located at the back of the tracker

Plug the HDMI cable in, this is how it should look:

Connect the other HDMI end to HDMI port on the right side of the monitor

Connect the other USB-C end of the 5V5A Raspberry Pi Power supply to the power port of the Raspberry Pi.

The Raspberry Pi power port is the leftmost port at the back of the

Connect all 3 Power supplies (Servo Motor Power, Raspberry Pi Power & Monitor Power) to a socket.

Connect the DC plug of the 12V Servo Motor Power Supply to the ESP32 Servo Motor Driver Power Port

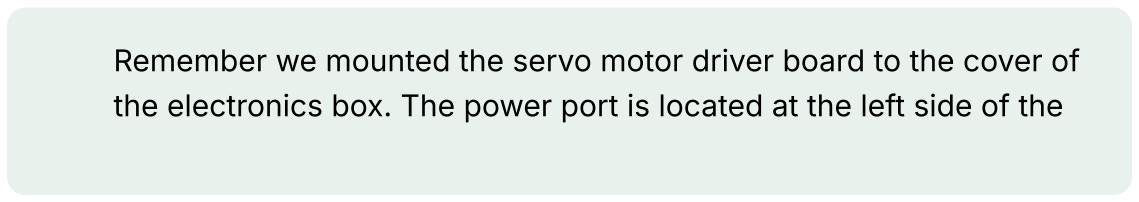
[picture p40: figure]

Remember we mounted the servo motor driver board to the cover of the electronics box. The power port is located at the left side of the

box.

Plug it in and it should look like this:

Connect the USB-C Power for the Monitor

You should see that the ESP32 servo motor driver board displays:
”Searching Servos … MAX_ID 20-Ping:4 Detected: 1 2”

Indicating it found motor ID 1 and Motor ID 2, corresponding to the two motors we have:

It would quickly turn to “SERIAL_FORWARDING” mode automatically, allowing us to control the motors using the Raspberry Pi.

After all of this, you should see the desktop of the Raspberry Pi on the monitor

And now we are finally ready to run code on the tracker robot

### Part 2: Reading the motor values & Basic Controls

Now you should be able to see the desktop of the Raspberry Pi.

Let’s try to run some program and control the human tracking robot

First press on Ctrl + Shift + T on your keyboard. The terminal will pop up.

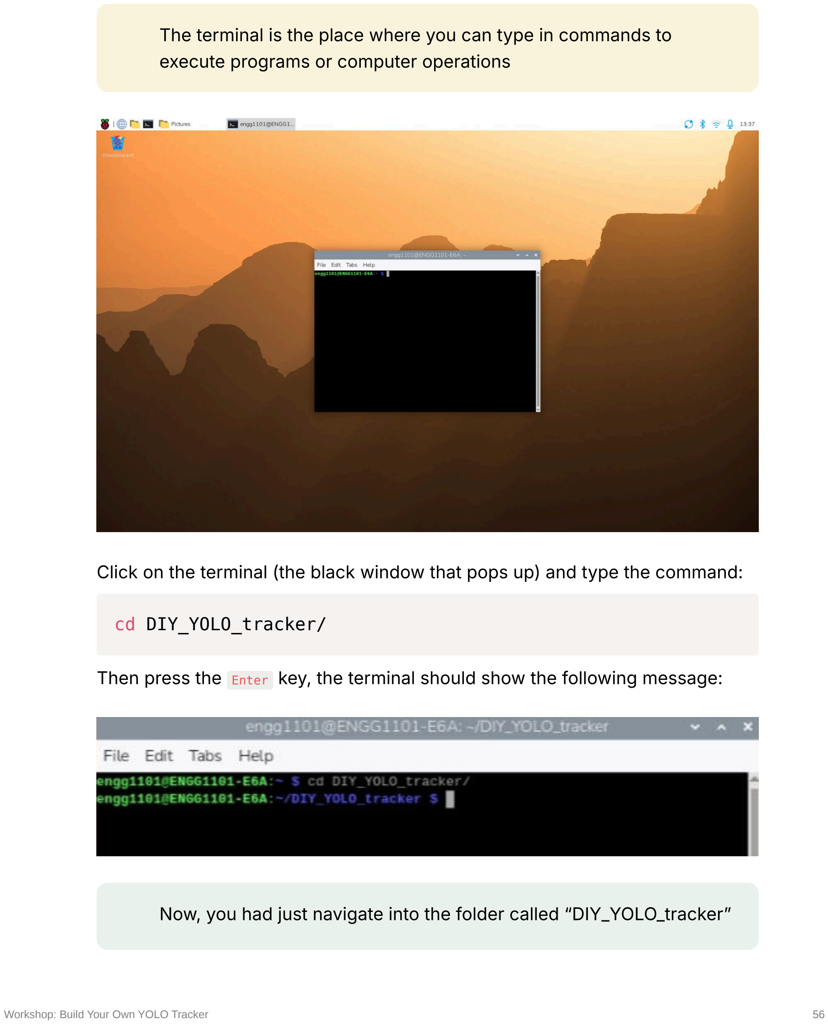
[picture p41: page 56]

The terminal is the place where you can type in commands to execute programs or computer operations

Click on the terminal (the black window that pops up) and type the command:

cd DIY_YOLO_tracker/

Then press the Enter key, the terminal should show the following message:

Now, you had just navigate into the folder called “DIY_YOLO_tracker”

Next, center the YOLO tracker robot so that the camera faces the front horizontally, like this:

Type the following command:

python3 gimbal_controller.py

This command allows you to run the python code

Then press the Enter key, the terminal should show the following message:

Showing the control keys (use left/right arrows to control yaw rotation ……)

Current position of the servo motors

Remember this center value of servos 1&2, we will use it later.

For mine the center position of servo 1 is 227 and center position of servo 2 is
2485
IMPORTANT | : RECORD THE INITIAL POSITION OF BOTH
MOTORS !!!
IMPORTANT | : RECORD THE INITIAL POSITION OF BOTH
MOTORS !!!
IMPORTANT | : RECORD THE INITIAL POSITION OF BOTH
MOTORS !!!

Now you can try pressing the arrow keys on the keyboard to manual control the robot

Controlling the robot manually is not dun, let’s try to make it auto

### Part 3: Changing the code and running the tracking program

Let’s first move back to the desktop.

Then click on the “File Manager” icon on the left upper corner.

Once the File Manager pops up you should be under the home directory.

Click onto the Folder: “DIY_YOLO_tracker”

Once you opened the “DIY_YOLO_tracker” , you should able to see the following:

This is where we stored our program in Part 2

Now, click into the “YOLO_tracker” folder, you should be able to see:

Click and open the “yolotracker.py” python file. The python script should pop up:

Now, we need to change the code based on our previous servo

Change lines 38 & 43 values to what you recorded in Part 2

(remember for my device is Servo 1 = 227 & Servo 2 =2485)

Replace the value of self.servo_horizontal_start (line 38) to YOUR servo 1 value

Replace the value of self.servo_vertical_start (line 43) to YOUR servo 2 value

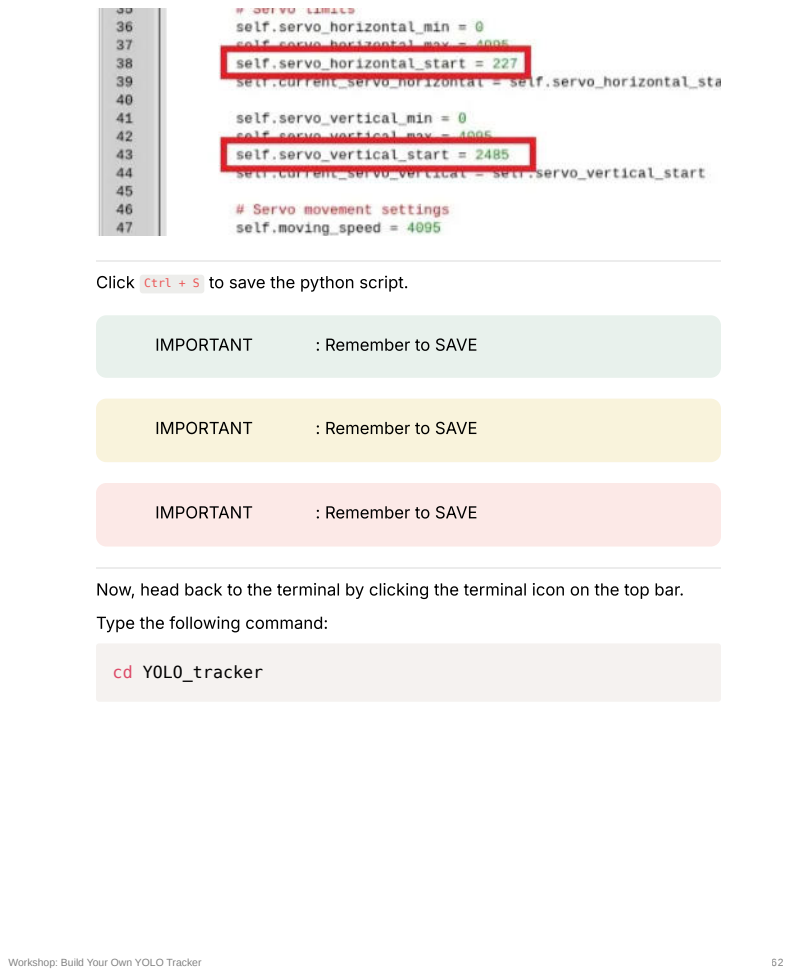
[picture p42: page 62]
IMPORTANT; : Remember to SAVE; cd YOLO_tracker

Click Ctrl + S to save the python script.

Now, head back to the terminal by clicking the terminal icon on the top bar.
Type the following command:

We are now inside the YOLO_tracker directory where we just modified

Type the following command:

source yolo_env/bin/activate

You should see (yolo_env) in the front of the line, stating we activated the virtual environment which includes the libraries we need to use.

Type the following command:

python3 yolotracker.py

This runs the tracker program and enjoy playing with the robot

You should be able to see the camera view popping up and a cross mark appears to track your head (only heads, not the whole body)

Yea, and that is me.
Great shoutout and thanks to Dr. Ryan Wang for setting up the YOLO tracker topic for ENGG1101 mini-projects which lay the foundations of this workshop
Also, a lot of thanks to 2026 Semester ENGG1101 Group M5 for providing the base code and fundamental concepts during their mini-project developments.

# Summary

What you have done in this workshop:

1. Assemble a YOLO Human Tracker Robot successfully as a team.
2. Modify Python Code according to servo initial positions
3. Enjoy playing with the tacker robot
4. Start your journey as an engineer, Welcome to the family.

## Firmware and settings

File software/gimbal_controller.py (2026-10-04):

#!/usr/bin/env python3
"""Manual controller for a two-axis STS3215 camera gimbal.

The workshop hardware uses servo ID 1 for yaw and servo ID 2 for pitch.
Both servos share a serial bus connected through the ESP32 driver board.
"""

from __future__ import annotations

import argparse
import os
import sys
import time
from contextlib import contextmanager
from dataclasses import dataclass
from typing import Iterator

try:
    from scservo_sdk import COMM_SUCCESS, PortHandler, sms_sts
except ImportError as exc:  # pragma: no cover - depends on workshop hardware
    raise SystemExit(
        "Missing Feetech SDK. Install it with: "
        "python3 -m pip install ftservo-python-sdk"
    ) from exc


POSITION_MIN = 0
POSITION_MAX = 4095


@dataclass(frozen=True)
class Axis:
    name: str
    servo_id: int
    minimum: int
    maximum: int
    inverted: bool = False

    def clamp(self, value: int) -> int:
        return max(self.minimum, min(self.maximum, value))


class GimbalController:
    """Small reusable interface around the Feetech STS3215 SDK."""

    def __init__(
        self,
        port: str,
        baudrate: int,
        yaw: Axis,
        pitch: Axis,
        speed: int = 500,
        acceleration: int = 50,
    ) -> None:
        self.port_name = port
        self.baudrate = baudrate
        self.yaw = yaw
        self.pitch = pitch
        self.speed = speed
        self.acceleration = acceleration
        self.port_handler = PortHandler(port)
        self.packet_handler = sms_sts(self.port_handler)
        self.targets: dict[int, int] = {}
        self.centers: dict[int, int] = {}

    def open(self) -> None:
        if not self.port_handler.openPort():
            raise RuntimeError(f"Could not open serial port {self.port_name}")
        if not self.port_handler.setBaudRate(self.baudrate):
            self.port_handler.closePort()
            raise RuntimeError(f"Could not set baud rate to {self.baudrate}")

        for axis in (self.yaw, self.pitch):
            model, result, error = self.packet_handler.ping(axis.servo_id)
            self._check(result, error, f"ping {axis.name} servo")
            print(
                f"Detected {axis.name} servo: ID {axis.servo_id}, "
                f"model {model}"
            )

        self.record_centers()

    def close(self) -> None:
        self.port_handler.closePort()

    def _check(self, result: int, error: int, action: str) -> None:
        if result != COMM_SUCCESS:
            detail = self.packet_handler.getTxRxResult(result)
            raise RuntimeError(f"Failed to {action}: {detail}")
        if error:
            detail = self.packet_handler.getRxPacketError(error)
            raise RuntimeError(f"Servo error while trying to {action}: {detail}")

    def read_position(self, axis: Axis) -> int:
        position, result, error = self.packet_handler.ReadPos(axis.servo_id)
        self._check(result, error, f"read {axis.name} position")
        return int(position)

    def read_positions(self) -> tuple[int, int]:
        return self.read_position(self.yaw), self.read_position(self.pitch)

    def record_centers(self) -> tuple[int, int]:
        yaw_position, pitch_position = self.read_positions()
        self.centers = {
            self.yaw.servo_id: yaw_position,
            self.pitch.servo_id: pitch_position,
        }
        self.targets = dict(self.centers)
        return yaw_position, pitch_position

    def move(self, axis: Axis, position: int) -> int:
        position = axis.clamp(position)
        result, error = self.packet_handler.WritePosEx(
            axis.servo_id, position, self.speed, self.acceleration
        )
        self._check(result, error, f"move {axis.name} servo")
        self.targets[axis.servo_id] = position
        return position

    def nudge(self, axis: Axis, amount: int) -> int:
        direction = -1 if axis.inverted else 1
        current_target = self.targets[axis.servo_id]
        return self.move(axis, current_target + amount * direction)

    def center(self) -> None:
        self.move(self.yaw, self.centers[self.yaw.servo_id])
        self.move(self.pitch, self.centers[self.pitch.servo_id])


@contextmanager
def keyboard_input() -> Iterator[None]:
    """Put a terminal into immediate key-reading mode and restore it later."""
    if os.name == "nt":
        yield
        return

    import termios
    import tty

    file_descriptor = sys.stdin.fileno()
    original = termios.tcgetattr(file_descriptor)
    try:
        tty.setcbreak(file_descriptor)
        yield
    finally:
        termios.tcsetattr(file_descriptor, termios.TCSADRAIN, original)


def read_key() -> str:
    if os.name == "nt":
        import msvcrt

        first = msvcrt.getwch()
        if first in ("\x00", "\xe0"):
            return {
                "K": "left",
                "M": "right",
                "H": "up",
                "P": "down",
            }.get(msvcrt.getwch(), "unknown")
        return "escape" if first == "\x1b" else first.lower()

    first = sys.stdin.read(1)
    if first != "\x1b":
        return first.lower()

    # Arrow keys arrive as a three-byte ANSI escape sequence.
    import select

    sequence = ""
    for _ in range(2):
        readable, _, _ = select.select([sys.stdin], [], [], 0.05)
        if not readable:
            return "escape"
        sequence += sys.stdin.read(1)
    return {
        "[D": "left",
        "[C": "right",
        "[A": "up",
        "[B": "down",
    }.get(sequence, "escape")


def show_status(controller: GimbalController) -> None:
    yaw = controller.targets[controller.yaw.servo_id]
    pitch = controller.targets[controller.pitch.servo_id]
    print(
        f"\rYaw ID {controller.yaw.servo_id}: {yaw:4d}  |  "
        f"Pitch ID {controller.pitch.servo_id}: {pitch:4d}    ",
        end="",
        flush=True,
    )


def run_keyboard(controller: GimbalController, step: int) -> None:
    yaw_center = controller.centers[controller.yaw.servo_id]
    pitch_center = controller.centers[controller.pitch.servo_id]
    print("\nKeyboard control active")
    print("  Left/Right : yaw (servo ID 1 by default)")
    print("  Up/Down    : pitch (servo ID 2 by default)")
    print("  C           : return to recorded center")
    print("  R           : record the current positions as new centers")
    print("  P           : read and print measured positions")
    print("  Esc or Q    : quit")
    print(f"\nRecorded center - yaw: {yaw_center}, pitch: {pitch_center}")

    with keyboard_input():
        show_status(controller)
        while True:
            key = read_key()
            if key in ("escape", "q"):
                break
            if key == "left":
                controller.nudge(controller.yaw, -step)
            elif key == "right":
                controller.nudge(controller.yaw, step)
            elif key == "up":
                controller.nudge(controller.pitch, step)
            elif key == "down":
                controller.nudge(controller.pitch, -step)
            elif key == "c":
                controller.center()
            elif key == "r":
                yaw, pitch = controller.record_centers()
                print(f"\nNew center - yaw: {yaw}, pitch: {pitch}")
            elif key == "p":
                yaw, pitch = controller.read_positions()
                print(f"\nMeasured position - yaw: {yaw}, pitch: {pitch}")
            else:
                continue
            time.sleep(0.02)
            show_status(controller)
    print()


def position_value(value: str) -> int:
    number = int(value)
    if not POSITION_MIN <= number <= POSITION_MAX:
        raise argparse.ArgumentTypeError(
            f"position must be between {POSITION_MIN} and {POSITION_MAX}"
        )
    return number


def build_parser() -> argparse.ArgumentParser:
    parser = argparse.ArgumentParser(
        description="Control a two-axis STS3215 camera gimbal with arrow keys."
    )
    parser.add_argument("--port", default="/dev/ttyUSB0")
    parser.add_argument("--baudrate", type=int, default=115_200)
    parser.add_argument("--yaw-id", type=int, default=1)
    parser.add_argument("--pitch-id", type=int, default=2)
    parser.add_argument("--step", type=int, default=32)
    parser.add_argument("--speed", type=int, default=500)
    parser.add_argument("--acceleration", type=int, default=50)
    parser.add_argument("--yaw-min", type=position_value, default=POSITION_MIN)
    parser.add_argument("--yaw-max", type=position_value, default=POSITION_MAX)
    parser.add_argument("--pitch-min", type=position_value, default=POSITION_MIN)
    parser.add_argument("--pitch-max", type=position_value, default=POSITION_MAX)
    parser.add_argument("--invert-yaw", action="store_true")
    parser.add_argument("--invert-pitch", action="store_true")
    parser.add_argument(
        "--calibrate-only",
        action="store_true",
        help="read and display both center positions without entering control mode",
    )
    return parser


def main() -> int:
    args = build_parser().parse_args()
    if args.yaw_min > args.yaw_max or args.pitch_min > args.pitch_max:
        raise SystemExit("Each minimum position must be less than its maximum.")
    if args.yaw_id == args.pitch_id:
        raise SystemExit("Yaw and pitch must use different servo IDs.")
    if args.step <= 0 or args.speed < 0 or not 0 <= args.acceleration <= 254:
        raise SystemExit("Use step > 0, speed >= 0, and acceleration from 0 to 254.")

    yaw = Axis("yaw", args.yaw_id, args.yaw_min, args.yaw_max, args.invert_yaw)
    pitch = Axis(
        "pitch", args.pitch_id, args.pitch_min, args.pitch_max, args.invert_pitch
    )
    controller = GimbalController(
        args.port,
        args.baudrate,
        yaw,
        pitch,
        speed=args.speed,
        acceleration=args.acceleration,
    )

    try:
        controller.open()
        yaw_center = controller.centers[yaw.servo_id]
        pitch_center = controller.centers[pitch.servo_id]
        print(f"Current center - yaw: {yaw_center}, pitch: {pitch_center}")
        if not args.calibrate_only:
            run_keyboard(controller, args.step)
    except (KeyboardInterrupt, RuntimeError) as exc:
        print(f"\n{exc}", file=sys.stderr)
        return 1
    finally:
        controller.close()
    return 0


if __name__ == "__main__":
    raise SystemExit(main())

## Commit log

2026-10-04 Add camera tracker CAD files
    [10_20_5_bearing.SLDPRT, 15_35_bearing.SLDPRT, 30_42_7_bearing.SLDPRT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]
2026-10-04 Reorganize camera tracker CAD files
    [10_20_5_bearing.SLDPRT, 15_35_bearing.SLDPRT, 30_42_7_bearing.SLDPRT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]
2026-10-04 Rename easy version to educational version
    [10_20_5_bearing.SLDPRT, 30_42_7_bearing.SLDPRT, ENGG1101_webcam.SLDPRT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]
2026-10-04 Add workshop materials and STS3215 gimbal controller
2026-10-04 Document Raspberry Pi scservo SDK control
